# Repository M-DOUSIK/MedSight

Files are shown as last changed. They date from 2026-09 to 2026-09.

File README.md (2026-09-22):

# MedSight

**An offline medication dispenser and adherence recorder.**
Most dispensers release pills and assume the rest. This one measures who took
them and how many came out.

Built on µT-Kernel 3.0 and an STM32N6570-DK, with no radio of any kind in this
build - connectivity is planned work, not a rejected idea.

**TRON Programming Contest 2026 · RTOS Application category ·
Entry 54916**

🔗 **[m-dousik.github.io/MedSight](https://m-dousik.github.io/MedSight/)** - the
project site, with the device running.

---

A carer enrols a patient once - face, name, dose size and the times of day they
take it - behind a passcode. From then on the device recognises the patient by
face, reminds them when a dose is due, turns a stepper-driven turntable while an
infrared sensor counts each pill physically leaving it, runs action recognition
over the confirmation window, and writes what happened to a local SD card.

**It counts pills leaving the turntable and corroborates a swallowing gesture. It
cannot prove that a medication was ingested.** No device of this class can. The
action recognition is corroboration only, by design, and the button confirms
every dose. [`docs/MEDSIGHT_HANDBOOK.md`](docs/MEDSIGHT_HANDBOOK.md) is the full account
and is the document to read first.

---

## Where to start

| If you are... | Read |
|---|---|
| **new to this** | [`docs/MEDSIGHT_HANDBOOK.md`](docs/MEDSIGHT_HANDBOOK.md) - what the device is, how it works, how to run it, how to build and flash it, and what comes next. Also the copy printed and shipped in the box: [print edition PDF](pdf/MedSight_Handbook_PRINT.pdf) |
| **looking at the hardware** | [`docs/HARDWARE_SPEC.md`](docs/HARDWARE_SPEC.md) - annotated parts, wiring, bill of materials, specifications |
| **evaluating the engineering** | [`docs/TECHNICAL_REFERENCE.md`](docs/TECHNICAL_REFERENCE.md) - software, AI, memory, and every measured number with how it was obtained |
| **checking provenance** | [`docs/THIRD_PARTY_SOFTWARE.md`](docs/THIRD_PARTY_SOFTWARE.md) and [`docs/LICENSING.md`](docs/LICENSING.md) |
| **holding a device whose mechanism will not move** | [`docs/MEDSIGHT_HANDBOOK.md`](docs/MEDSIGHT_HANDBOOK.md) 8.9. One macro and a rebuild runs everything except the physical dispense, with no motor, driver or sensor attached |

**Six documents.** The handbook is also a print edition:
[`pdf/MedSight_Handbook_PRINT.pdf`](pdf/MedSight_Handbook_PRINT.pdf).

## The numbers

Every figure is measured on the real board and named with how it was obtained
in [`docs/TECHNICAL_REFERENCE.md`](docs/TECHNICAL_REFERENCE.md). None
is an estimate.

| | Measured |
|---|---|
| **CPU idle** | **~89.6%** of wall-clock time asleep in `WFI`, waking ~980×/s. The vendored BSP ships `low_pow()` **empty** |
| **Face recognition** | **209 ms** end to end - detector, embedder and the RTOS IPC between them - **identical to the millisecond across four captures** with different faces and confidences |
| **Memory footprint** | `.text` 561,324 · `.rodata` 334,456 · `.data` 684 · `.bss` 656,488 - 85.6% of the code region, 63.0% of the data region |
| **Pill detector** | 8-bit integer on the NPU with the decode on the Cortex-M55. The quantisation matches floating point on the validation set; at the deployment distance per-frame detection is about 7%, so it corroborates rather than decides |
| **IR pill counting** | real pulses **17-46 ms**, chatter 0-1 ms, floor set at 8 ms - all measured before any threshold was chosen |
| **Dispense counting** | 4 trials, all 13 pills counted by the sensor rather than by the motor. A small sample, and not a reliability figure: the mechanism has miscounted and jammed outside these trials |
| **µT-Kernel surface** | tasks, event flags, alarm handlers, a message buffer, one mutex and the idle hook. Every call lives in `ms_osal.c`; the vendored kernel is unmodified except for six files, none of which implements a system call |
| **The assembled unit** | **165 x 169 x 204 mm** and **950 g** with the turntable empty, tape measure and kitchen scales against the built device. 15 mm of the depth is the collection drawer standing proud of the body |

The 209 ms is the same on every capture: four images, four detector
confidences, one timing. The Neural-ART runtime executes a fixed epoch schedule
for a fixed input shape, so the cost does not depend on image content, which is
why the display holds still for the capture window instead of showing a
spinner.

## What makes this a µT-Kernel application, specifically

The category is judged on real-time performance, power saving and memory
footprint. The answer is not "we used an RTOS":

| Primitive | What it does here |
|---|---|
| `tk_cre_tsk` | **Six tasks**, priorities derived rate-monotonically. The AI task sits *below* the interface deliberately, which is what keeps touch and the physical button alive while the accelerator works |
| `tk_cre_flg`, `tk_wai_flg` | **Inference is dispatched through an event flag.** One blocking call distinguishes face found, no face, and no answer at all. A queue, a semaphore or a mutex cannot say that |
| `tk_cre_alm`, `tk_sta_alm` | **Dose scheduling is an alarm handler**, not a task polling the clock. Polling would wake 8,640 times a day in order to act four times. The handler sets one bit and returns; every line of real work is done by a task |
| `tk_cre_mbf`, `tk_cre_mtx` | The logger's queue, so no caller ever waits on an SD write, and the firmware's one mutex: the clock, which has two readers |
| `low_pow()` | The vendored board support package ships its idle hook **empty**. Ours executes `WFI` and accounts for the cycles, which is where the 89.6% comes from |

**A single file reaches the kernel.** Every call above lives in `ms_osal.c`, behind
an abstraction the rest of the firmware was written against, so the kernel's
use is deliberate and in one place rather than scattered. Two idioms were
evaluated and deliberately not adopted, with the reasoning recorded: a
fixed-size memory pool, and an event flag for the confirm state. Neither would
have done any work here.

## The AI, and which models are ours

| Network | Decides | Origin | Licence |
|---|---|---|---|
| CenterFace | Detects a face and emits five landmarks with it, both mouth corners among them | STMicroelectronics | SLA0044 |
| MobileFaceNet | Encodes the face crop as a 128-dimension embedding for cosine matching | STMicroelectronics | SLA0044 |
| MediaPipe hand landmarks | 21 keypoints, giving the fingertip position during the confirmation window | Google. **Not ours** - we selected, quantised, compiled and integrated it; we did not train it | Apache-2.0 |
| **Pill detector** | Single-class detection in a mouth-centred region. Corroboration only | **Trained by this project** | AGPL-3.0, from the training framework, [resolved](docs/LICENSING.md) |

Everything around the face networks is this project's code: the frame snapshot,
the CenterFace box decode, L2 normalisation, int8 quantisation, cosine gallery
matching and SD persistence.

The pill detector was trained here on a public pill dataset, exported, and
adapted to the accelerator: the convolutional body runs as 8-bit integer on the
NPU and the YOLO decode runs on the Cortex-M55. On the validation set the 8-bit
model matches the floating-point one it was trained from, but at the deployment
distance a pill is about an 8-pixel object and per-frame detection is around
7%, so it corroborates the hand geometry rather than deciding on its own.

It carries **AGPL-3.0** because Ultralytics YOLOv8 trained it and that licence
follows the weights, so the whole training pipeline is published with them in
[`tools/pill_detector/`](tools/pill_detector/).

## Data handling

**This build has no radio.** Wi-Fi, Ethernet and BLE are never initialised,
and no code path can transmit anything off-device.

**Connectivity is planned work**: a carer alert over Wi-Fi when a dose is
missed, and a patient-worn band that signals when a dose is due. The handbook's
last part sets out what that has to answer first: transport security, what the
message carries, where the data comes to rest, provisioning, and what happens
when the link is down.

**What follows from having no radio today:** patient names, face embeddings
and the adherence log cannot leave the SD card over a network, because there is
no network. That is a consequence of the scope decision rather than its motive,
so it changes when the radio arrives.

**The unit as shipped has no card fitted.** Its slot is on the board, inside
the housing, and the card is supplied alongside rather than installed. Until it
is fitted the home screen says so in those words, nothing is recorded, and the
enrolled gallery and the carer passcode last only until the power is cut.
Everything else runs exactly as described.

Face embeddings are never written to UART or to any log; only names, gallery
slot indices, dose counts, schedule times and match confidences are. That rule
was checked against a captured UART log from the noisiest build that exists,
not only by reading the source.

The patient record is five fields: a validity flag, a name, a 128-byte
embedding, a dose size, and up to four dose times. No phone number, no address,
no date of birth, no medical history. What is stored for face recognition is a
quantised embedding, **not the enrolment photograph** - the camera frame that
produced it is never written to the card.

Full posture, including the gaps, in
[`docs/MEDSIGHT_HANDBOOK.md`](docs/MEDSIGHT_HANDBOOK.md).

## Building it

This firmware starts from ST's STM32N6 example application and replaces its
core: µT-Kernel 3.0 is the RTOS, and the OS abstraction layer, the interface,
the state machine, the scheduler, the logger and the dispenser driver are
original MedSight code. Every third-party component and its licence is
inventoried in [`docs/THIRD_PARTY_SOFTWARE.md`](docs/THIRD_PARTY_SOFTWARE.md).

**STM32CubeIDE 2.1.1** or newer. There is **no `.ioc` file** - every peripheral
is configured in code rather than generated, so there is nothing to
regenerate.

```
firmware/STM32CubeIDE/FSBL     <- import this, build Debug
```

Expect **0 errors, 0 warnings**. Both `MEDSIGHT_PHYSICAL_DISPENSER` 1 and 0
build clean; `0` runs the whole application with **no dispensing hardware
attached**, which is a supported configuration rather than a debug path. That
branch is the earlier on-screen dispense kept byte-for-byte, and it has been
run on the assembled board rather than only compiled.

> **Building is not enough to get a working device.** The NPU weights live in
> external flash and the linker marks those regions `(NOLOAD)`, so the
> application build never writes them. Flash the five images in
> [`weights/`](weights/) once per board, then power-cycle. Without them the
> firmware runs and both AI features return nonsense, **with nothing in the log
> to say why.**

Complete instructions, every command of which was actually run:
[`docs/MEDSIGHT_HANDBOOK.md`](docs/MEDSIGHT_HANDBOOK.md) Part 3.

## Licence - is this open source?

**Yes.** MedSight's own code, documentation and CAD are released under
**Apache-2.0**, an OSI-approved open-source licence: read it, build it, change
it, ship it, including commercially, keeping the notice.

The repository is more a **shelf** than a **book** - every item carries its own
licence, and one of them is not open source: ST's AI runtime, camera ISP and
the two face models are under **ST SLA0044**, which permits free redistribution
for use on ST hardware but is not an open-source licence. Every STM32 AI project
carries that, and it blocks nothing.

**MedSight's own code is Apache-2.0.** The repository is **not licensed as a
single work** - it vendors µT-Kernel under T-License, ST components under
BSD-3-Clause and SLA0044, a Google model under Apache-2.0, and FatFs under its
own licence.

[`docs/LICENSING.md`](docs/LICENSING.md) is the per-file map, and it also
**resolves the AGPL-3.0 question** on the pill detector rather than leaving it
open: the project adopts Ultralytics' own stated reading, complies with it for
the detector's artefacts, licenses its own code permissively so the question
cannot bind anything else, and names the one residual incompatibility along with
the build-verified configuration that avoids it.

## Layout

```
MedSight/
  index.html, site.css   the project site (GitHub Pages serves this)
  media/                 the hero loop and its poster
  firmware/              the complete firmware - build this
  hardware/cad/          STL files for the three printed assemblies
  weights/               NPU weight blobs, addresses and fingerprints
  docs/                  everything above, and the engineering record
  pdf/                   the handbook, print edition
  research/              the evidence base, with licences
  tools/                 the model training pipeline and asset generators
```

**The handbook is also a print edition**, laid out to be read rather than
filed: [`pdf/MedSight_Handbook_PRINT.pdf`](pdf/MedSight_Handbook_PRINT.pdf).

## Where it stands

It is a working prototype, and four things are not finished. Each has a plan,
and the handbook's last part sets all of them out properly.

- **One turntable, so one medication.** Next: the stacked dispensing modules already drawn
  in the hardware specification, plus a drug field in the patient record. The
  interface draws the extra slots today, greyed out.
- **It cannot see how full the turntable is.** Next, and the cheapest of these: a
  carer-entered fill count, decremented by *counted* pills, shown as a low
  stock warning on screens that already exist.
- **A missed dose cannot leave the room**, because there is no radio in this
  build. Next, and the top of the list: a carer alert over Wi-Fi and a
  patient-worn band, with the security design that has to come with them.
- **The housing does not lock.** Next: a lockable enclosure, tamper detection
  and a vibration sensor, so the log can say when the unit was disturbed.

And one thing to be clear about rather than plan around: the device counts
pills out and corroborates a swallowing gesture. It cannot prove somebody
swallowed, and no device of this class can, which is why the patient's button
press stays the confirming action.

## Credit

MedSight was built by five of us.

| | |
|---|---|
| **Dousik Manokaran** (applicant) | The firmware: the µT-Kernel migration, the six-task architecture and its priorities, the four networks on the accelerator, and the documentation |
| **Howard Nikhil** | The physical dispensing hardware: the turntable, the infrared pill counter, and the bench work the counting design rests on |
| **Gaurav V R** and **Dillimaran K** | The three-stage intake pipeline - detection, geometry, temporal decision - and the guarded state machine that refuses to certify an intake it cannot support |
| **Abirami M** | The visual identity: the mascot, and the artwork all twenty-two screens are cut from |
| **Dr. G. Santhanamari** and **Dr. D. Selvakumar** | Supervision, and two roadmap items: the vibration sensor for tamper detection, and the patient-worn alert band |

Our thanks to the TRON Forum for the opportunity, and for the STM32N6570-DK
board that made the second round possible.

µT-Kernel 3.0 is (c) TRON Forum and Ken Sakamura, under T-License 2.1 /
2.2, and the STM32N6570-DK was supplied by the TRON Forum for the second round.

Third-party components and their licences are inventoried in
[`docs/THIRD_PARTY_SOFTWARE.md`](docs/THIRD_PARTY_SOFTWARE.md).

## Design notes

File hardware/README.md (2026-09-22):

# hardware/

The hardware **documents** live in `../docs/`, with everything else, so that
every relative link between documents resolves the same way:

| Document | What it is |
|---|---|
| [`../docs/HARDWARE_SPEC.md`](../docs/HARDWARE_SPEC.md) | **the whole hardware document** - annotated parts view, the eleven wires, the bill of materials, the specifications block, the power path and the bring-up order |
| [`../docs/MEDSIGHT_HANDBOOK.md`](../docs/MEDSIGHT_HANDBOOK.md) | Part 4 is the same material laid out for somebody holding a jumper wire |

This directory holds the **files**: `cad/` for the printed parts.

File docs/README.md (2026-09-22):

# docs/

| Document | What it is |
|---|---|
| [`MEDSIGHT_HANDBOOK.md`](MEDSIGHT_HANDBOOK.md) | **Start here.** What the device is, how it works, how to run it, how to build and flash it, and what comes next. Also the print edition, [`pdf/MedSight_Handbook_PRINT.pdf`](../pdf/MedSight_Handbook_PRINT.pdf) |
| [`HARDWARE_SPEC.md`](HARDWARE_SPEC.md) | Annotated parts, the eleven wires, the bill of materials, the specifications, the power path and the bring-up order |
| [`TECHNICAL_REFERENCE.md`](TECHNICAL_REFERENCE.md) | Part A the RTOS, Part B the software structure, Part C the AI pipeline, Part D memory, Part E every measured number and how it was obtained |
| [`THIRD_PARTY_SOFTWARE.md`](THIRD_PARTY_SOFTWARE.md) | Name, rights holder, acquisition and function of every third-party component, the µT-Kernel modification table, and the rights guarantee |
| [`LICENSING.md`](LICENSING.md) | Which licence governs which files, and whether this project is open source |
| [`PROGRAM_PLAN_RECONCILIATION.md`](PROGRAM_PLAN_RECONCILIATION.md) | What the March 2026 plan promised against what was built, in both directions |

Also here: [`slides/`](slides/), the introduction slides as a PowerPoint
file, and [`images/`](images/).

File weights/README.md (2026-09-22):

# NPU weights - what to flash, where, and why the firmware is useless without it

Everything in this directory is **NPU model data that the firmware build does
not contain**. The linker marks the external NOR regions `(NOLOAD)` on purpose,
so building and flashing the application never writes any of it.

That means a fresh clone can compile a perfectly good `.elf`, flash it, and get
a device whose face recognition and action recognition both produce garbage -
with nothing in any log to say why. **Flash these once per board.**

## The five images

| file | address | bytes | what it is |
|---|---|---|---|
| `fd_data.xSPI2.bin` | `0x70380000` | 2,030,881 | CenterFace - face detector constant pools |
| `ec_blobs.xSPI2.bin` | `0x71000000` | 296,832 | NPU epoch-controller microcode, **both** face networks |
| `faceid_data.xSPI2.bin` | `0x72000000` | 1,092,129 | MobileFaceNet - face embedder constant pools |
| `hand_atonbuf.xSPI2.bin` | `0x73000000` | 3,221,233 | MediaPipe hand landmarks, decides a dose |
| `pill_atonbuf.xSPI2.bin` | `0x73400000` | 3,049,169 | YOLOv8n pill detector, corroboration only |

SHA-256 prefixes, so a mis-copied file is caught before it becomes a debugging
session:

```
8076b74352f3c323  ec_blobs.xSPI2.bin
68a41c8a030afde3  faceid_data.xSPI2.bin
44f72b41a1f43183  fd_data.xSPI2.bin
a0cb24315860ddae  hand_atonbuf.xSPI2.bin
e1359bb6add1268f  pill_atonbuf.xSPI2.bin
```

## Flashing

```powershell
$cli    = "C:\ST\STM32CubeIDE_2.1.1\STM32CubeIDE\plugins\com.st.stm32cube.ide.mcu.externaltools.cubeprogrammer.win32_2.2.500.202603051304\tools\bin\STM32_Programmer_CLI.exe"
$loader = "C:\ST\STM32CubeIDE_2.1.1\STM32CubeIDE\plugins\com.st.stm32cube.ide.mcu.externaltools.cubeprogrammer.win32_2.2.500.202603051304\tools\bin\ExternalLoader\MX66UW1G45G_STM32N6570-DK.stldr"

& $cli -c port=SWD mode=UR -el $loader -w "weights\fd_data.xSPI2.bin"        0x70380000
& $cli -c port=SWD mode=UR -el $loader -w "weights\ec_blobs.xSPI2.bin"       0x71000000
& $cli -c port=SWD mode=UR -el $loader -w "weights\faceid_data.xSPI2.bin"    0x72000000
& $cli -c port=SWD mode=UR -el $loader -w "weights\hand_atonbuf.xSPI2.bin"   0x73000000
& $cli -c port=SWD mode=UR -el $loader -w "weights\pill_atonbuf.xSPI2.bin"   0x73400000
```

### `mode=UR`, not `mode=HOTPLUG`

This page said `mode=HOTPLUG` for two years, and it was right for two years:
the only writes happened before any application existed on the board, and
HOTPLUG avoids holding the MCU in reset while the external loader talks to the
flash chip.

Once a bootable MedSight image went into external flash, that changed. HOTPLUG needs a live, responsive core to attach to - and with
MedSight **running**, the erase fails outright, because the application has
XSPI2 memory-mapped for these very weights while the loader wants the same bus
in indirect mode.

**Use `mode=UR` for writes to external flash.** It holds the target in reset,
so it does not care what the application was doing. The commands above have
been updated.

### Then POWER-CYCLE. Unplug the USB cable.

Not a reset, not the IDE's stop button - the cable, out, for a few seconds.

Back-to-back external-loader operations leave the flash chip's live bus state
confused, and the symptom is a boot that hangs where XSPI is first touched:
the log stops right after `ai_vision_init: DEBUG build (-O0).`, before
`HAL_CACHEAXI_Enable`, and the LCD holds a stale frame. The flash *contents*
are fine; only the peripheral's bus state needs clearing.

**This applies to reads as well as writes.** A `-r32` verification read leaves
the bus in the same state a write does, and a read is exactly when it is most
tempting to leave the board running.

### Verifying

```powershell
& $cli -c port=SWD mode=UR -el $loader -r32 0x73000000 2
```

Compare against the file's own first words, then power-cycle again:

```bash
python -c "import struct;print('0x%08X 0x%08X' % struct.unpack('<II', open('weights/hand_atonbuf.xSPI2.bin','rb').read(8)))"
```

`0x73000000` should read `0xB317E9A4`, `0x73400000` should read `0xF0010DF7`.

## Confirming it worked

A correct boot says, in this order:

```
ai_vision_init: face detector + embedder ready.
ARENA SELFTEST PASS: 225280 bytes writable and readable
intake: hand landmark model ready (MediaPipe 224x224 INT8, 21 keypoints, ...)
intake: pill detector ready (YOLOv8n 160x160 INT8, head cut, decode on CPU).
```

A missing or wrong image usually does **not** announce itself as a flash
error - it shows up as a network that initialises and then returns nonsense.
If detection runs but the numbers are meaningless, suspect a weight region
before suspecting the code.

## Where these come from

* **`fd_data`, `faceid_data`, `ec_blobs`** - generated once and unchanged
  since. Byte-identical across every build that used them, which is how the
  copies here were validated. The epoch-controller data's source of
  truth is the tracked headers `FSBL/Inc/fd_ecblobs.h`, `faceid_ecblobs.h` and
  `network_ecblobs.h`; `ec_blobs.xSPI2.bin` is a packaging of the same content
  for the programmer.
* **`hand_atonbuf`** - ST model zoo `pose_estimation/handlandmarks`,
  Apache-2.0, regenerated against `medsight_hand.mpool`.
* **`pill_atonbuf`** - the hard-negative retrain, regenerated against
  `medsight_pill2.mpool` so it does not collide with the hand model.

Regenerating either model is in `tools/pill_detector/build_pill_detector.py`. Note
that a regenerated model changes its INT8 quantisation scales, which live in
`Inc/stai_*.h` - **so a weights change always requires a firmware rebuild**,
even though the firmware does not contain the weights.

## Why this directory exists at all

These blobs used to live only inside `firmware/STM32CubeIDE/FSBL/Debug/
weights_flash/`, i.e. inside build output. When build output stopped being
tracked, that silently removed the only copies of the face-network weights
from the repository. The check that authorised the removal looked for
hand-written source and found none, which was the wrong question: not
hand-written is not the same as regenerable, and for the face networks there
is no regeneration path in this repository at all.

Irreplaceable binary assets do not belong in a directory that a `.gitignore`
rule can sweep away.

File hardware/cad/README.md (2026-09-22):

# The printed parts

Three printed assemblies, designed in Autodesk Fusion.

Each part is here twice: an **STL** to print from, and a **STEP** to open and
change. The STL is a triangle mesh and cannot meaningfully be edited; the STEP
carries the solid geometry.

| Part | Print | Edit | Size (STL bounding box) | Triangles |
|---|---|---|---|---|
| Board enclosure | `board_enclosure.stl` | `board_enclosure.step` | **164.24 × 153.00 × 151.99 mm** | 10,766 |
| Pill dispenser mechanism | `pill_dispenser.stl` | `pill_dispenser.step` | **179.24 × 92.00 × 50.00 mm** | 5,136 |
| Structural pillars, 8 off | `structural_pillars.stl` | `structural_pillars.step` | **180.00 × 100.00 × 10.00 mm** | 96 |

`HARDWARE_DESIGN_SHEET.pdf` is a one-page annotated summary of all three.

Numbered callouts for every sub-part, and what each one does, are in
[`../../docs/HARDWARE_SPEC.md`](../../docs/HARDWARE_SPEC.md).

Printed FDM in PLA at 20% infill.

## Licensing

Original designs by this project, under **Apache-2.0**, the same as the rest of
MedSight's own work. See [`../../docs/LICENSING.md`](../../docs/LICENSING.md).

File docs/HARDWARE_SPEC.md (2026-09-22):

# The hardware, part by part

Parts, wiring, bill of materials, specifications and the order to power things
up in.

---

## 1. The annotated view

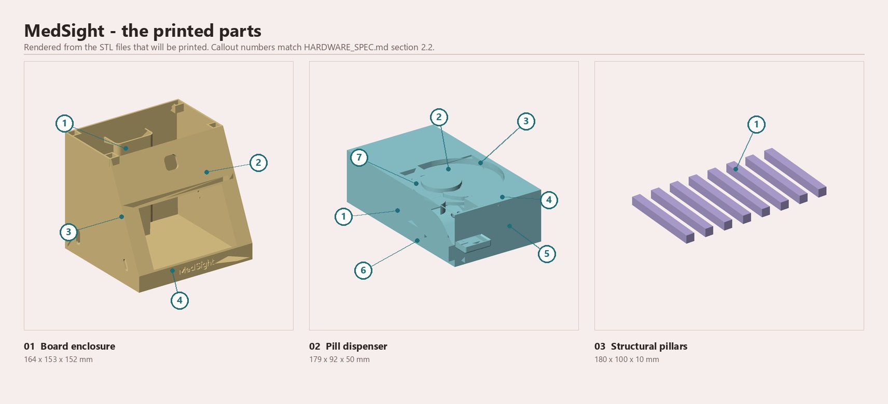
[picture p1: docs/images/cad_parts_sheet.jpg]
The three printed parts, rendered from their STL files with numbered callouts


*The three printed assemblies. Callout numbers resolve to the tables in
section 2.*

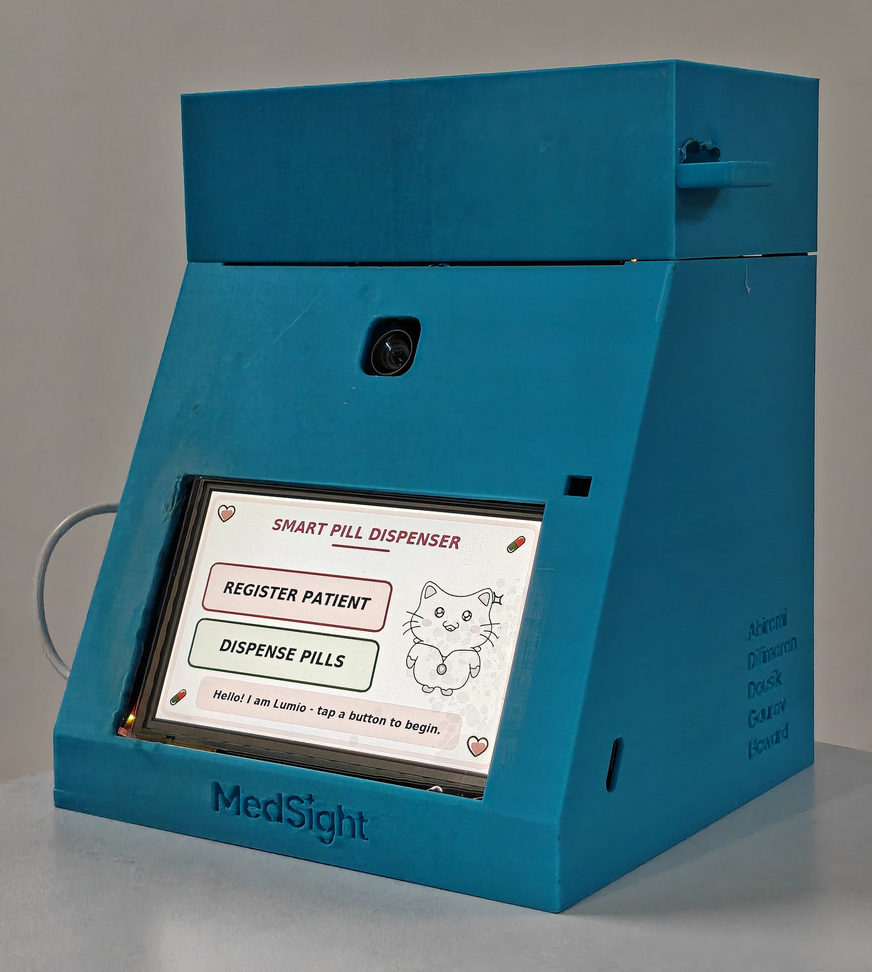
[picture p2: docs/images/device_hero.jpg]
The assembled device seen from the front left, the 5 inch screen lit on the home screen with its two buttons, the camera above the screen and the MedSight name on the front base


*The assembled unit. The camera sits above the screen, the collection drawer is
at the lower right, and the five names on the side panel are the people who
built it.*

---

## 2. Parts, by callout number

Every number in the annotated view resolves to a row here. The board's own
components are listed too, so that what was used and what was merely present
are both visible.

### 2.1 Electronics

| # | Part | Manufacturer / part number | Qty | Function | Source |
|---|---|---|---|---|---|
| **1** | STM32N6570-DK Discovery kit | STMicroelectronics, **STM32N6570-DK** (MCU: STM32N657X0H3Q) | 1 | The whole computer: Cortex-M55 at 800 MHz, Neural-ART NPU at 1 GHz, ~4.2 MB on-chip SRAM. Runs µT-Kernel 3.0 and all four networks. | Supplied by the contest for round 2 |
| **2** | 5" LCD with integrated capacitive touch | **RK050HR18** panel + **GT911** touch controller (both on the DK) | 1 | The entire user interface: 22 screens at 800×480 RGB565, scanned out by the LTDC. Touch on I2C2 (PD14/PD4). | On the DK board |
| **3** | Camera module | **IMX335** sensor on ST's MB1854 / B-CAMS-IMX bundle, via DCMIPP + CSI | 1 | Face capture for recognition and enrolment; the intake watch during the confirm screen. | Shipped with the DK |
| **4** | microSD card | any FAT32 card, on the DK's SDMMC2 slot | 1 | The only storage: patient gallery `patients.dat`, append-only `events.log`, carer passcode hash `carer.cfg`. **Nothing leaves this card.** | User-supplied |
| **5** | Stepper motor | **28BYJ-48**, 5 V, unipolar, 1/64 geared | 1 | Turns the turntable. Driven in a half-step sequence; each half-step is one atomic `BSRR` write. | Sold as a pair with (6) |
| **6** | Darlington driver board | **ULN2003A** on the common 4-LED breakout | 1 | Switches the four motor coils from four 3.3 V GPIO lines. The four channel LEDs are a free bring-up indicator. | ships with (5) |
| **7** | IR proximity module | 3-pin digital module, **`OUT` not analog** | 1 | Counts each pill as it physically passes. This is the sensor the whole dispense loop closes around - the progress bar is a readout of this interrupt, not a timer. | generic |
| **8** | Piezo buzzer | **active** piezo element (contains its own oscillator) | 1 | Five alert patterns. Driven by plain push-pull GPIO, DC switched - no PWM, no timer channel, no transistor, no resistor. | generic |
| **9** | Jumper wires | female-to-female | **11** | The entire wiring harness. **No resistors, no transistors, no level shifters, no external regulator.** Buy 14 - they are sold in packs and they break | generic |
| **10** | USB-C cable + 5 V supply | any; a 10 000 mAh / 22.5 W USB battery pack was used | 1 | Single supply for board, driver and sensor. One 5 V source, one ground. | generic |

**Why there are no external passives.** An early design called for pull-down
resistors on the ULN2003 inputs. Checking TI's datasheet **SLRS027T** section 7.2-7.3
showed the ULN2003A has an **internal input network** - 2.7 kΩ series plus
7.2 kΩ/3 kΩ base-emitter pull-downs - so the inputs do not float. The
requirement was dropped, and the bill of materials is the shorter for it.

### 2.2 Printed and mechanical parts

Three printed assemblies. Every dimension is the STL bounding box.

#### 01 - Board enclosure · 164 × 153 × 152 mm · 10,766 triangles

Houses the STM32N6570-DK and presents the 5" screen at a readable angle. The
sloped front face is the reason the device reads as an appliance rather than a
dev board on a desk.

| # | Part | Function |
|---|---|---|
| **1** | Outer housing shell | The main enclosure body, with sloped structural walls |
| **2** | Port / connector grid | A grid of circular openings on the side wall for the I/O the board needs to reach - USB-C, the jumper harness out to the dispenser |
| **3** | Battery compartment | Rear-mounted cuboid recess for the battery pack. **This is what makes standalone operation a product feature rather than a demo**: the battery lives inside the device rather than trailing from it |
| **4** | MedSight brand plate | Embossed panel on the front base face |

#### 02 - Pill dispenser · 179 × 92 × 50 mm · 5,136 triangles

The mechanism. One turntable, one medication - which is where classification
happens in this device, mechanically rather than by vision.

| # | Part | Function |
|---|---|---|
| **1** | Outer enclosure box | Rectangular housing, open at the top over the turntable |
| **2** | Rotating pill carousel | The disc, with a helical pill track. Mounted on the 28BYJ-48 and driven half-step |
| **3** | Central drive motor hub | The spindle at the centre, coupling the stepper to the carousel |
| **4** | Dispensing chute | The exit channel to the collection drawer. **The chute geometry is what makes the IR counter work**: pills *slide* rather than free-fall, which is why detection pulses measure 17-46 ms instead of the few milliseconds a drop would give - and a driver sized for a free-fall would have discarded every real pill |
| **5** | Output collection drawer | The external box the dose arrives in |
| **6** | Side sensor brackets ×2 | Mounts that hold the infrared proximity module square to the chute at a repeatable height and standoff, which is what makes one pill's pulse look like the next one's |
| **7** | Internal divider wall | Vertical partition separating the mechanism from the pill storage volume |

#### 03 - Structural pillars · 180 × 100 × 10 mm · 8 off

| # | Part | Function |
|---|---|---|
| **1** | Structural pillar ×8 | Hollow rectangular-section beams forming the frame that carries the enclosure and the dispenser as one assembly |

### 2.3 The mechanism, and the stacked-module design it belongs to

**The turntable was designed and built by the team.** A small turntable with
passive guides singulates loose, unsorted pills into a single-file row, pushes
that row past an infrared proximity sensor, and drops counted pills down a chute. Pills
go in loose; the guides do the sorting mechanically, so there is no per-pill
compartment to align.

**One reflective sensor, with the threshold in hardware.** The module is a
reflective infrared proximity sensor: a pill passing in front of it returns
enough light to pull the output low, and because the output is digital the
in-or-out decision is made in the sensor rather than in software. One module
also means one alignment to hold rather than a facing pair to keep square.

**What that costs, stated rather than skipped.** How strongly a pill returns
light depends on its colour and finish, so this is not a sensor that is
indifferent to what is being counted. That is precisely why the discrimination
floor was set from measured pulse durations on the bench rather than assumed,
and why the counter is bounded by time since the last counted pill rather than
by an expected pulse shape.

**The stepper is a 28BYJ-48 through a ULN2003A**, driven directly in a half-step
coil sequence rather than through a STEP/DIR driver IC. It is cheap, it draws
little, it needs four GPIO lines, and it is trivial to duplicate per module.

#### The stacked-module architecture, which is design intent and not built

One module is built and works. The intended product is **six to eight
stacked independent dispensing modules**, each a duplicate of the one that exists, all
dropping into **one shared chute** so the patient collects a dose from a single
place.

Stacked independent modules were chosen over one larger multi-position carousel
for a reason that was about the deadline as much as the engineering: **you can
build two today and six later without redesigning anything.** A single large
carousel has to be built to full capacity before it is useful at all, its
capacity is fixed at print time, and one jam stops every medication rather than
one. The dispense API already takes a count and returns what was actually
counted, so adding a `module_id` is additive.

Turntable and guide geometry is the one part that is *not* copy-paste between
modules, because different medications have different pill sizes.

**The CAD files are in [`hardware/cad/`](../hardware/cad/)**, one STL and one
STEP per printed part: the STL is what a reader prints, the STEP is what a
reader can open and change. The print settings actually used are recorded in
`hardware/cad/README.md`. What is still missing there is a fastener list.

---

## 3. Interface and connector map

Wire by the **silkscreen label** printed next to each pin - that is the only
labelling that is unambiguous with a jumper in your hand. The MCU-pin column
exists so the table can be checked against `dispenser.c` and `buzzer.c`.

| Function | Silkscreen | Header | MCU pin | I/O domain |
|---|---|---|---|---|
| ULN2003 `IN1` - coil A | `D3` | CN11 | PE9 | VDDIO5 |
| ULN2003 `IN2` - coil B | `D5` | CN11 | PE10 | VDDIO5 |
| ULN2003 `IN3` - coil C | `D6` | CN11 | PE13 | VDDIO5 |
| ULN2003 `IN4` - coil D | `D9` | CN12 | PE14 | VDDIO5 |
| IR module `OUT` | `D2` | CN11 | PD0 (**EXTI0**, both edges) | main VDD |
| Piezo `+` | `D10` | CN12 | PA3 | main VDD |
| 5 V and GND for both modules | `5V` / `GND` | CN8 | - | - |

**Pins that must stay unwired:**

| Pin | MCU pin | Why |
|---|---|---|
| `D14` | PC1 | camera I2C1 SDA - in use |
| `D15` | PH9 | camera I2C1 SCL - in use |

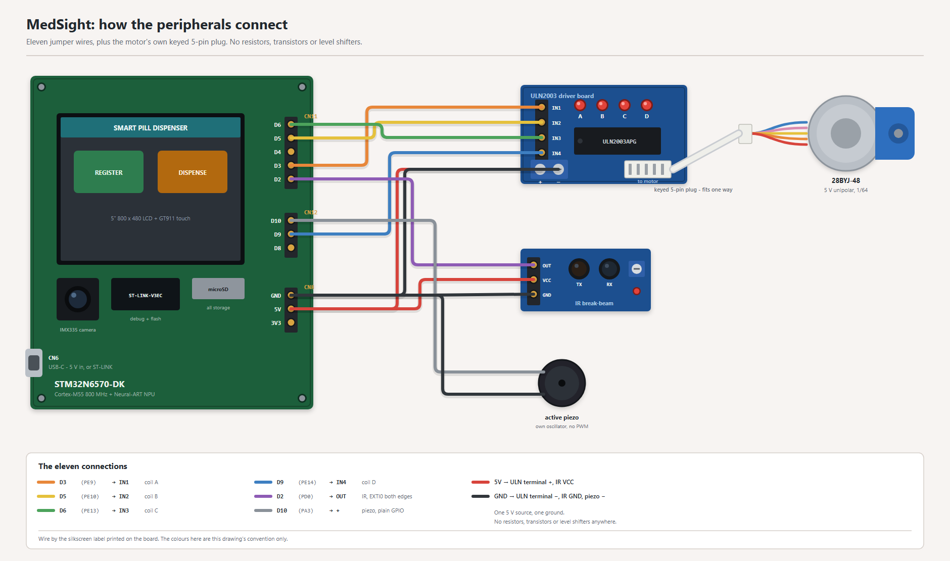
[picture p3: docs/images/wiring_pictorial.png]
How the peripherals connect


*Eleven jumper wires, plus the motor's own keyed 5-pin plug. Wire by the
silkscreen label - the colours above are the drawing's own convention. Generated
from the table above by `submission/render_wiring.py`, so the two cannot
disagree.*

Power path: section 9. Bring-up order: section 10.

---

## 4. Specifications

| | |
|---|---|
| **Processor** | Arm Cortex-M55 @ 800 MHz, STM32N657X0H3Q |
| **AI accelerator** | ST Neural-ART NPU @ 1 GHz, ~600 GOPS INT8 |
| **Networks running on it** | **4** - CenterFace (face detection), MobileFaceNet (face embedding), MediaPipe hand landmarks 224×224 INT8, YOLOv8n single-class pill detector 160×160 INT8 |
| **On-chip memory** | ~4.2 MB AXI SRAM in six banks; 220 KB proven NPU-reachable arena at `0x34388000` |
| **External memory** | 1 Gbit Octo-SPI NOR (NPU weights, four regions) · 256 Mbit Hexadeca-SPI PSRAM (activation scratch, camera frames) |
| **Firmware footprint (Debug)** | `.text` 561,324 · `.rodata` 334,456 · `.data` 684 · `.bss` 656,488 B - **85.6%** of the code region (147 KB free), **63.0%** of the data region (378 KB free) |
| **RTOS** | µT-Kernel 3.0 BSP2, six tasks, rate-monotonic priorities |
| **CPU idle** | **~89.6%** of wall-clock time in `WFI`, waking ~980×/s |
| **Display** | 5" RK050HR18, **800 × 480, RGB565**, LTDC scan-out, single framebuffer at `0x34200000` |
| **Touch** | GT911 capacitive, I2C2 |
| **Camera** | Sony IMX335 via DCMIPP + CSI |
| **Storage** | microSD (SDMMC2), FAT32 via FatFs R0.15. **The only persistent storage in the device.** |
| **Clock** | Internal RTC on LSE, falling back to LSI; kept across resets in the backup domain. **No NTP - there is no network.** |
| **Actuator** | 28BYJ-48 unipolar stepper, 1/64 gearbox, driven **half-step**; `MS_STEP_PERIOD_MS` = **2 ms** per half-step |
| **Pill sensor** | 3-pin digital IR proximity on EXTI0, both edges timestamped in the ISR. Idle **HIGH**. Real pill pulses **17-46 ms**; contact chatter 0-1 ms; discrimination floor **8 ms** |
| **Dispense bound** | `MS_NO_PILL_TIMEOUT_MS` = **25 s** since the *last counted pill* - a working mechanism runs as long as it needs to; a stopped one is caught in one window |
| **Audio** | Active piezo, 5 patterns, DC-switched GPIO. No codec, no PWM |
| **Power input** | 5 V over USB-C (CN6). Board, driver and sensor from one supply, one ground |
| **Power consumption** | **not measured.** See section 6 |
| **Boot modes** | **A** - development boot over USB with UART log. **B** - standalone from external NOR: ST FSBL at `0x70000000`, MedSight signed `-t ssbl` at `0x70100000`. Verified running a complete dispense on battery with no laptop |
| **Connectivity** | **None in this build.** Wi-Fi, Ethernet and BLE are never initialised and no network stack is compiled in. A scope decision, not a principle - connectivity is planned work, `MEDSIGHT_HANDBOOK.md` section 6.8 |
| **Capacity** | **multiple patients**, 4 dose times each, 1-10 pills per dose, **1 turntable**. The gallery is sized by `MAX_PATIENTS` in `ai_vision.h`, 10 in this build; raising it costs gallery RAM and nothing else |
| **Printed part sizes** | Board enclosure **164 × 153 × 152 mm** · pill dispenser **179 × 92 × 50 mm** · structural pillars **180 × 100 × 10 mm** (8 off), read from the STL bounding boxes |
| **Assembled dimensions** | **165 x 169 x 204 mm** (W x D x H), tape measure against the assembled unit. 15 mm of the depth is the collection drawer, which stands proud of the body |
| **Mass** | **950 g**, assembled, turntable empty |
| **Turntable capacity** | **Not a fixed number, by the nature of the mechanism.** Pills lie loose in a single layer on an open turntable and the guides singulate them, so there is no point at which it fills and binds. How many go in depends on pill size and how tidily they are laid out |
| **Power-source jumper** | On the underside of the board, selecting `VIN`, `USB-C` or `STLK`. **USB-C** to run from the battery, **STLK** to build and flash over the debugger. Ships on USB-C |
| **Operating environment** | Indoor, mains or battery, room temperature. No environmental qualification of any kind has been performed |

**How these figures were obtained.** The envelope and the mass were measured
against the assembled unit, with a tape measure and kitchen scales. Capacity
was not measured, because the mechanism has no point at which it binds: pills
lie loose in one layer and the guides do the singulating, so any single number
would have to be invented in order to be stated.

---

## 5. Measured performance

Every number here was taken on the real board. Where a figure names a count of
trials, that count is the real one.

| Quantity | Value | How it was obtained |
|---|---|---|
| Face recognition, end to end | **209 ms**, identical to the millisecond across **four** captures with different faces and confidences | The invariance is the point: the Neural-ART runtime executes a fixed epoch schedule for a fixed input shape, so cost does not depend on image content |
| Failed capture | 1111 ms | three detector passes plus two 500 ms waits |
| Hand-landmark inference | **285-302 ms** | ST publishes 20.75 ms for this model - an all-internal figure; ~978 KB of our activations sit in PSRAM |
| Pill detector on the NPU | 8-bit integer, decode on the Cortex-M55, **matching its floating-point accuracy** | held-out validation |
| Dispense accuracy | 4 trials: 5/5, 3/3, 3/3, 2/2. All 13 pills counted, by the sensor rather than the motor. A small sample, and the mechanism has miscounted and jammed outside these trials | not a reliability figure |
| Longest *legitimate* detection pulse | **1210 ms** | the number that killed an earlier 1500 ms stall bound, which had left 290 ms of margin before it would have refused a dose that was being delivered correctly |
| Half-step period | 2 ms | smooth and silent under turntable load |
| Battery operation | 1 complete dispense, battery alone, no laptop | standalone boot |
| CPU idle | **~89.6%** in `WFI`; **7-50%** during an intake watch, which is 0.14% of a four-dose day - a daily average of ~87.9% | DWT cycle counts accumulated across the sleep, read out from a task on a 10-second period |

---

## 6. What is on the board and deliberately unused

The board carries more than this build uses. Each one, and why.

| Capability | Why it is unused |
|---|---|
| **Gigabit Ethernet** | Never initialised in this build, and no code path can transmit. Connectivity is planned work; `MEDSIGHT_HANDBOOK.md` section 6.8 |
| **USB data (device and host)** | Only ST-LINK debug and flashing are used. A USB data path would be a route off the device, which is the same argument as Ethernet. |
| **Wi-Fi / BLE** | Not present on the board and nothing is added to the BOM. A carer alert over Wi-Fi and a patient-worn band are the top of the roadmap, and both need a module this hardware does not have. |
| **SAI audio codec and MEMS microphone** | The one event that needs sound is a missed dose, and an active piezo on a GPIO does that for one wire and no code. A codec is neither needed nor in scope. `HAL_SAI_MODULE_ENABLED` is still commented out. |
| **The second XSPI / unused external NOR regions** | The NPU weights occupy four regions; the rest is unclaimed. Documented in `TECHNICAL_REFERENCE.md` section 8 so a future model has somewhere known to go. |
| **Power measurement** | The DK supports instrumented power measurement and **it was never wired up**. The ~89.6% idle figure is a *duty-cycle* measurement from DWT cycle counts, not milliwatts. No power figure in watts is claimed anywhere in this submission, because none was measured. |

---

## 7. The enclosure, stated plainly

**The housing is a prototype shell. It does not lock. There is no tamper
detection.**

This is stated in the hardware document, at this size, because it is a
mechanical property that has a regulatory consequence: residential-care
regulation in most jurisdictions requires medication to be stored **locked**,
and a reader who assumed otherwise would be wrong about where this device can
be deployed today.

The *withholding* is real - the device refuses to release a dose outside its
window, and refuses to release it to a face it does not recognise. **The lock
is not.** Those are different properties, and only one of them is built.

A lockable enclosure, tamper detection and a vibration sensor are the plan for
a complete product. They are future work, in the future tense, and no part of
them is present in the device that ships. `MEDSIGHT_HANDBOOK.md` section 6.4 is the full
argument.

---

## 8. Configuration switches

All are plain macros in the sources. There is **no `.ioc` file** - every
peripheral is configured by hand - so nothing needs regenerating.

| Macro | File | Default | Effect |
|---|---|---|---|
| `MEDSIGHT_PHYSICAL_DISPENSER` | `Inc/dispenser.h` | `1` | `0` runs everything except the physical dispense with **no dispensing hardware attached**, shown on screen instead. A supported configuration, not a debug path, and run on the assembled board. Use it if the mechanism is damaged or missing |
| `MEDSIGHT_ACTION_RECOGNITION` | `Inc/ai/intake.h` | `1` | `0` removes the intake pipeline entirely - verified to drop **every** `stai_pill*` symbol from the ELF. Also the AGPL-free configuration; see `LICENSING.md` section 3 |
| `MEDSIGHT_INTAKE_SIMPLE` | `Inc/ai/intake.h` | `1` | `0` restores the full guarded intake state machine. See `MEDSIGHT_HANDBOOK.md` section 4.7 for why the default is `1` |
| `MS_COIL_PINSET` | `Src/dispenser.c` | `1` | `1` = `D3/D5/D6/D9`. `0` selects an alternative coil pin set |
| `MS_DISPENSE_DIRECTION` | `Src/dispenser.c` | `(-1)` | The turntable turns **anticlockwise** to dispense. `1` is clockwise. Flips the dispensing rotation and the settle-back together, which must always oppose each other |
| `MS_NO_PILL_TIMEOUT_MS` | `Src/dispenser.c` | `25000` | How long with no counted pill before JAM or SHORT |
| `MEDSIGHT_BUZZER_KEYBOARD_CLICK` | `Inc/buzzer.h` | `0` | `1` ticks on every keypress. Off because a device that beeps on every tap is tiring to use |
| `MEDSIGHT_FAST_CLOCK` | build config | Debug `1`, Release `0` | Compresses a day into 24 minutes - one simulated minute per real second |

---

## 9. Power path

One 5 V source, one ground.

**Before any of it: the power-source jumper.** On the underside of the board is
a jumper selecting where the board takes its power from, with positions `VIN`,
`USB-C` and `STLK`. It must be on **USB-C** to run from the battery, and on
**STLK** to build and flash over the debugger. It ships on USB-C.

It is worth stating plainly because the failure it causes is silent: on the
wrong position the board draws nothing, the screen stays dark, and there is no
message to read. That looks like a dead board and it is a jumper.

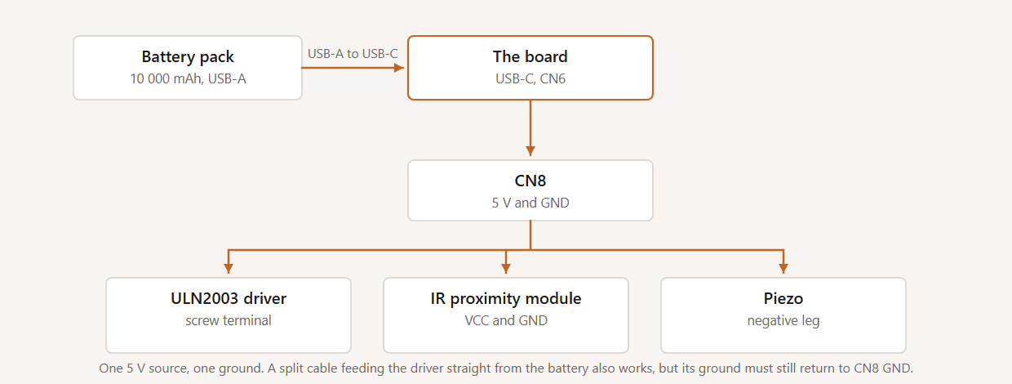
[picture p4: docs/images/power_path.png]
The power path: the battery reaches the board over USB-C, and the driver, the infrared module and the piezo all take 5 V and ground from the board's own CN8 header


Running the ULN2003 from the board's own CN8 `5V` was tested and works
flawlessly, including under motor load. That is the recommended arrangement
because it makes a shared ground structural rather than something you have to
remember.

A split USB cable feeding the ULN2003 straight from the battery pack also works
- but **its ground must still return to CN8 `GND`**. A driver whose ground
floats relative to the MCU will not switch, and the failure looks exactly like
a dead driver: no LEDs, no motion, no error.

For standalone operation set **BOOT1 (SW1) LOW** so the board boots the signed
image from external flash instead of waiting for a debugger. The handbook's
build section covers how that image is signed and flashed.

---

---

## 10. Bring-up order, if you are wiring from scratch

Run in this order. Each step is independently observable, so a failure tells
you which of the eleven wires to look at.

1. **Power only.** Board boots to the MedSight UI. No peripheral wired yet.
2. **Buzzer.** Wire `D10` and `GND`. Tapping the keypad should tick.
3. **IR module.** Wire `OUT`/`VCC`/`GND`. The module's own LED changes state
   when you pass a finger in front of it. The line idles HIGH and pulls LOW
   while broken; real pill breaks measure **17-46 ms**, and anything under
   8 ms is discarded as contact chatter.
4. **ULN2003, no motor.** Wire `IN1`-`IN4` and power. Start a dispense - the
   four channel LEDs should chase in sequence. If they do not light at all,
   go to section 6 and to the ground note in section 4.
5. **Motor.** Plug in the JST. The turntable turns **anticlockwise**, the
   direction that feeds the chute. A differently-handed turntable needs
   `MS_DISPENSE_DIRECTION` changed rather than the coils rewired: it flips
   the dispensing rotation and the settle-back together, which must always
   oppose each other.
6. **Full dispense.** Register a patient, request a dose, watch the on-screen
   progress bar step once per counted pill.

A dispense that counts nothing for 25 seconds reports **JAM** (nothing was
released). One that counts some but not all of the requested pills and then
goes quiet for 25 seconds reports **SHORT** - the turntable needs refilling.
Neither is an error condition and neither calls `Error_Handler()`; both are
normal outcomes of a mechanical device and are recorded in the audit log with
the count that was actually delivered.

---

---

## See also

| Document | What it is |
|---|---|
| `HARDWARE_SPEC.md` section 3 | the pin budget and the reasoning behind it |
| `HARDWARE_SPEC.md` section 2.3 | the turntable and guide geometry, and the stacked-module design intent |
| [`TECHNICAL_REFERENCE.md`](TECHNICAL_REFERENCE.md) | Part C: where every byte on the part lives |
| [`MEDSIGHT_HANDBOOK.md`](MEDSIGHT_HANDBOOK.md) | the device, how to run it, and what comes next |

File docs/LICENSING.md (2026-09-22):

# Licensing

## Is this open source?

**Yes.** MedSight's own code, documentation and CAD are **Apache-2.0**. Read,
build, change, redistribute and sell, keeping the copyright notice and stating
what was changed.

## The repository is multi-licensed

Each component carries the licence its own rights holder grants. `LICENSE` at
the repository root says so and points here.

| What | Licence | Open source |
|---|---|---|
| MedSight firmware, documentation, CAD, tools | Apache-2.0 | Yes |
| Pill detector weights and training pipeline | AGPL-3.0 | Yes |
| µT-Kernel 3.0 BSP2 | T-License 2.1 / 2.2 | Yes |
| CMSIS, STM32N6xx device layer | Apache-2.0 | Yes |
| STM32N6xx HAL/LL, board support package | BSD-3-Clause | Yes |
| MediaPipe hand landmark model | Apache-2.0 | Yes |
| FatFs R0.15 | FatFs licence | Yes |
| DejaVu Sans glyph data | Bitstream Vera / DejaVu | Yes |
| **ST Edge AI runtime, ISP library, the two face models** | **ST SLA0044** | **No** |

**SLA0044 is the only component that is not open source.** It is ST's code for
driving their own accelerator and camera, free to redistribute for use on ST
devices, and every STM32 AI project carries it.

## The pill detector and AGPL-3.0

The detector's weights were trained by this project with Ultralytics YOLOv8,
which is AGPL-3.0, and Ultralytics states that models trained with it are
AGPL-3.0 too.

**This project complies with that.** The complete corresponding source is
published in `tools/pill_detector/`: the training script, the dataset identity
and licence, the trained weights, the exported model before and after the head
was cut, and the accelerator build configuration. The network clause never
applies, because the device has no network.

**One incompatibility is real.** AGPL-3.0 and ST's SLA0044 cannot both govern a
single distributed binary, so no linked binary is distributed: the submission
conveys source and the recipient builds it. Setting
`MEDSIGHT_ACTION_RECOGNITION` to 0 is an AGPL-free configuration, verified by
symbol count.

## Per-file map

| Path | Licence |
|---|---|
| `firmware/FSBL/Src/`, `firmware/FSBL/Inc/`, except the AI files below | Apache-2.0 |
| `firmware/FSBL/Src/ai/ai_vision.c`, `intake*.c`, `npu_init.c` | Apache-2.0 |
| `firmware/FSBL/Src/ai/pill.c`, `stai_pill.c`, and the pill weight blob | AGPL-3.0 |
| `firmware/FSBL/Src/ai/hand.c`, `stai_hand.c`, and the hand weight blob | Apache-2.0 |
| `firmware/FSBL/Src/ai/fd.c`, `faceid.c`, `stai_fd.c`, `stai_faceid.c`, and their weight blobs | ST SLA0044 |
| `firmware/FSBL/Src/ai/ll_aton*.c` and the runtime archive | ST SLA0044 |
| `firmware/FSBL/mtk3_bsp2/` | T-License 2.1 / 2.2 |
| `firmware/Drivers/CMSIS/` | Apache-2.0 |
| `firmware/Drivers/STM32N6xx_HAL_Driver/`, `firmware/Drivers/BSP/` | BSD-3-Clause |
| `firmware/Middlewares/ST/STM32_ISP_Library/` | ST SLA0044 |
| `firmware/Middlewares/Third_Party/FatFs/` | FatFs licence |
| `hardware/cad/`, `docs/`, the site, `tools/` except the pill detector | Apache-2.0 |
| `tools/pill_detector/` | AGPL-3.0 |

**Not in this repository:** ST's prebuilt first-stage bootloader, used only for
boot from external flash. It is ST's binary, downloaded from ST directly; the
handbook gives the link and a fingerprint.

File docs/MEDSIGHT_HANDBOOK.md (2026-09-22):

# MedSight

**An offline medication dispenser that recognises the patient by face and counts
every pill physically leaving the turntable.**

TRON Programming Contest 2026 · RTOS Application category
Entry 54916 · Applicant: Dousik Manokaran

Source code and everything else: **github.com/M-DOUSIK/MedSight**

---

What the device is, how it works, how to run it, how to build and flash it,
and the planned work.

| Part | | |
|---|---|---|
| **1** | System overview | the problem, and what the device does about it |
| **2** | The dose sequence | five stages, end to end |
| **3** | The neural networks | four networks on the accelerator, no cloud |
| **4** | RTOS architecture | six tasks, and the kernel primitives in use |
| **5** | Hardware architecture | wiring, printed parts, specifications |
| **6** | Quick start | ninety seconds, no computer |
| **7** | Operation | every screen and every flow |
| **8** | Building and flashing the firmware | ST-LINK, step by step |
| **9** | Troubleshooting | fault diagnosis |
| **10** | Current limitations and planned work | the roadmap |

---

## Part 1. System overview

### The problem

**Between a fifth and a half of older patients do not take their long-term
medication as prescribed.** The range is **21-55%**, from a 2026 systematic
review of older adults facing treatment burden (Amato et al.), and a second
2026 review across **128 studies** searched to the end of 2024 finds the
problem no less stubborn (Scotti et al.). On dispensing data rather than
self-report, an analysis of **42,601 records** for patients over 65 lands in
the same place (Cardona et al., 2025). The familiar line that adherence
averages 50% comes from the WHO's 2003 review; that report established the
baseline and is cited here for that, not as a current measurement.

In residential care it fails differently, and worse. A study of **256 residents
across 55 care homes** found **69.5% had at least one medication error**, at a
mean of 1.9 errors each, with residents taking a mean of 8 medicines. The causes
named were not carelessness: high staff workload, lack of medicines training,
**drug round interruptions**, paper records, and administration systems that are
hard to fill and hard to check.

This is getting larger everywhere. **By 2030 one person in six worldwide
will be 60 or over**, and that population doubles to 2.1 billion by 2050 (World
Health Organization, October 2025). Care work is the constraint on top of it:
the same body projects a shortfall of about **11 million health workers by
2030**, concentrated in low- and lower-middle-income countries.

Most pill organisers are passive. A labelled box does not know who opened it, or
whether anything was taken.

### What the device does

A carer enrols a patient once: their face, their name, how many pills they take
at a time, and up to four times of day. That takes about two minutes and it
happens behind a passcode.

From then on the device runs on its own. It reminds the patient when a dose is
due. It checks who is standing in front of it, by face, using its own neural
processor. It turns a motorised turntable and **counts each pill as it
physically passes an infrared sensor**, so the number on screen is a
measurement rather than an assumption. It runs action recognition over the
confirmation window. And it writes every one of those events to a memory card that a carer
can read back on the device itself.

One device, many patients. Each one is recognised by face and carries their own schedule, up to four dose times a day. One medication per turntable.

### How it differs from existing dispensers

**It counts, rather than assumes.** Any dispenser can turn a motor for a fixed
time and hope the right number of pills came out. This one has a sensor in the
chute, and the progress bar on screen steps once per pill it actually detects.
If three pills come out when four were asked for, the record says three.

**It knows who it is dispensing to.** Face recognition runs entirely on the
board, on a dedicated neural processor, in **209 ms**. Nothing is uploaded and
no photograph is stored: what is kept is a mathematical fingerprint of the face,
not the picture that produced it.

**It runs on its own.** Signed firmware in the board's external flash, its own
battery in the back of the housing, no computer anywhere. It is a device, not a
demo.

**It does not need anyone's servers.** A dispenser with a companion app and an
account necessarily moves the adherence record off the device and onto somebody
else's machine. This build has no radio at all, so the record stays on the card
in the device.

---

## Part 2. The dose sequence

Five steps. The fourth is the one that matters.

| | | |
|---|---|---|
| **1** | **The window opens** | A µT-Kernel alarm handler fires exactly once. The home screen names the patient and the time; three short beeps. |
| **2** | **Identification** | CenterFace detects the face, MobileFaceNet encodes it as a 128-dimension embedding, and it is matched against the enrolled gallery by cosine similarity. **209 ms**, every time. |
| **3** | **Dispense** | The turntable turns. Each pill passes the infrared sensor on its way down the chute. Measured pulse: **17-46 ms**, because pills slide rather than fall. |
| **4** | **Counted, not timed** | The progress bar steps **once per counted pill**. Pill 3 of 6 is a half-full bar reading 50% because three pills were actually counted. |
| **5** | **Confirmation** | Action recognition observes the window. The patient's press of the large green button remains the confirming action. One record goes to the card. |

**Why step 4 is the one that matters.** With the mechanism attached the bar
advances on each sensor pulse, so it reports what the hardware actually did. A
timed animation exists only in the simulation build, where
`MEDSIGHT_PHYSICAL_DISPENSER` is 0 and there is no sensor to read. That is also
why the audit line records the count that actually came out:

```
DISPENSE: <patient> <n> requested, <m> counted (OK)
```

written once, after the outcome is known, so the log never contains two claims
about one event.

**If a dose goes wrong**, neither outcome is treated as a system fault, because
a mechanical device jamming is normal:

- **JAM** - 25 seconds with nothing counted at all. Nothing was released.
- **SHORT** - some pills, then 25 seconds of silence. The turntable needs refilling.

The 25 seconds measures **time since the last counted pill**, so a working
mechanism can take as long as it needs and a stopped one is caught in one
window.

---

## Part 3. The neural networks

Four neural networks run on the board's Neural-ART accelerator. Nothing is sent
anywhere.

| Network | What it decides | Origin |
|---|---|---|
| **CenterFace** | Detects a face and emits five landmarks with it, both mouth corners among them | STMicroelectronics |
| **MobileFaceNet** | Encodes the face crop as a 128-dimension embedding for cosine matching | STMicroelectronics |
| **MediaPipe hand landmarks** | 21 keypoints, giving the fingertip position during the confirmation window | Google, via ST's model zoo. We selected it, quantised it, compiled it to the NPU and integrated it. We did not train it |
| **Pill detector** | Single-class detection in a mouth-centred region. Corroboration only | **Trained by this team** |

The pill detector was trained here on a public pill dataset, exported, and
adapted to the accelerator: the convolutional body runs as 8-bit integer on the
NPU and the YOLO decode runs on the Cortex-M55. It corroborates and does not
decide, because at the deployment distance a pill is about an 8-pixel object
and per-frame detection is around 7%. On the validation set the 8-bit model
matches
the floating-point model it was trained from.

**Everything around the face networks is our code too**: the frame snapshot, the
box decode, the normalisation, the 8-bit quantisation of the fingerprint, the
cosine matching against the gallery, and writing it to the card.

**One measurement worth keeping.** The hand model scores 0.0078 on a face, never
goes above 0.035 across 400 random images, does not fire on an ear waved
deliberately in front of it, and scores about 0.50 on a hand at the mouth. Four
rounds of simpler skin-colour heuristics could not separate a moving ear from a
hand; a model that knows what a hand is settled it in one step.

---

## Part 4. RTOS architecture

This is entered in the RTOS Application category, judged on real-time
performance, power saving and memory footprint. The answer is not "we used an
RTOS".

| | |
|---|---|
| **89.6%** | of wall-clock time asleep in `WFI`, waking about 980 times a second |
| **85.6% / 63.0%** | of the code and data regions used, leaving 147 KB and 378 KB free |

### Kernel primitives in use

| Primitive | What it does here |
|---|---|
| `tk_cre_tsk` | **Six tasks**, priorities derived rate-monotonically: shortest period gets the highest priority, each number justified in writing. The AI task sits *below* the interface deliberately, which is what keeps touch and the physical button alive while the accelerator works |
| `tk_cre_flg`, `tk_wai_flg` | **Inference is dispatched through an event flag.** The interface's wait has three outcomes to tell apart in one blocking call: face found, no face, or the AI task never answered. A queue, a semaphore or a mutex cannot say that. The payoff is behavioural: the interface used to freeze inside the neural processor for seconds |
| `tk_cre_alm`, `tk_sta_alm` | **Dose scheduling is an alarm handler**, not a task polling the clock. Polling would wake 8,640 times a day in order to act four times, and would spend the power figure above doing it. The handler sets one bit and returns; every line of real work happens in a task |
| `tk_cre_mbf`, `tk_cre_mtx` | The logger's queue, so no caller ever waits on an SD write, and the firmware's one mutex: the clock, which has two readers |
| `low_pow()` | The vendored board support package ships its idle hook **empty**. Ours executes `WFI` and accounts for the cycles, which is where the 89.6% comes from |

**One file talks to the kernel.** Every call above lives in `ms_osal.c`, behind
an abstraction the rest of the firmware was written against, so the kernel's use
is deliberate and in one place rather than scattered. The vendored kernel itself
is unmodified except for six files out of about 230, none of which implements a
system call.

**Two idioms were evaluated and deliberately not adopted**, with the reasoning
written down: a fixed-size memory pool, because this firmware has no fixed-size
runtime allocation site at all and adopting one would have meant inventing an
allocation in order to have something to pool; and an event flag for the confirm
state, because all three of its conditions are produced by the task that would
wait on them. Neither would have done any work.

---

## Part 5. Hardware architecture

### Wiring and interconnects

How the peripherals connect

**Eleven jumper wires**, plus the motor's own keyed 5-pin plug into the driver
board. No resistors, no transistors, no level shifters, no external regulator.

| Wire | Board label | MCU pin | To |
|---|---|---|---|
| 1 | `D3` | PE9 | ULN2003 `IN1` (coil A) |
| 2 | `D5` | PE10 | ULN2003 `IN2` (coil B) |
| 3 | `D6` | PE13 | ULN2003 `IN3` (coil C) |
| 4 | `D9` | PE14 | ULN2003 `IN4` (coil D) |
| 5 | `5V` (CN8) | - | ULN2003 terminal `+` |
| 6 | `GND` (CN8) | - | ULN2003 terminal `-` |
| 7 | `D2` | PD0 | IR module `OUT` (interrupt, both edges) |
| 8 | `5V` (CN8) | - | IR module `VCC` |
| 9 | `GND` (CN8) | - | IR module `GND` |
| 10 | `D10` | PA3 | piezo `+` |
| 11 | `GND` (CN8) | - | piezo `-` |

**Wire by the silkscreen label** printed on the board, not by the colour in the
drawing. The colours above are that drawing's own convention.

`D14` and `D15` are the camera's I2C and must stay clear.

### Power

One 5 V source, one ground.

The power path: the battery reaches the board over USB-C, and the driver, the infrared module and the piezo all take 5 V and ground from the board's own CN8 header

Running the driver from the board's own `CN8 5V` was tested under motor load and
is the recommended arrangement, because it makes a shared ground structural
rather than something you have to remember. A split USB cable feeding the driver
straight from the battery pack works too, **but its ground must still return to
CN8 `GND`** - a driver whose ground floats will not switch, and it looks exactly
like a dead driver.

### The printed parts

The three printed parts, rendered from their STL files with numbered callouts

*Rendered from the STL files that go to the printer. The callout numbers are:*

| | |
|---|---|
| **01 Board enclosure** | 1 housing shell, 2 port and connector grid, 3 battery compartment, 4 MedSight brand plate |
| **02 Pill dispenser** | 1 enclosure box, 2 rotating carousel, 3 central drive motor hub, 4 dispensing chute, 5 output collection drawer, 6 side sensor brackets, 7 internal divider wall |
| **03 Structural pillars** | 1 structural pillar, eight off |

| Part | Size |
|---|---|
| Board enclosure | **164 x 153 x 152 mm** - sloped front face, rear battery compartment |
| Pill dispenser | **179 x 92 x 50 mm** - carousel, motor hub, chute, collection drawer, sensor brackets |
| Structural pillars, 8 off | **180 x 100 x 10 mm** |

**The chute geometry is what makes the counter work.** Pills slide rather than
free-fall, which is why detection pulses measure 17-46 ms instead of the few
milliseconds a drop would give. A driver sized for a free-fall would have thrown
away every real pill.

**One sensor, and a threshold set from measurement.** The module is a
reflective infrared proximity sensor: a pill passing in front of it returns
enough light to pull the output low, and the output is digital, so the
in-or-out decision is made in the sensor rather than in software. What that
costs is honest to state: how strongly a pill returns light depends on its
colour and finish, which is why the discrimination floor was set from measured
pulse durations rather than assumed.

### Specifications

| | |
|---|---|
| **Processor** | Arm Cortex-M55 at 800 MHz, STM32N657X0H3Q |
| **AI accelerator** | ST Neural-ART at 1 GHz, about 600 GOPS |
| **Networks on it** | 4 |
| **Memory** | ~4.2 MB on-chip SRAM · 1 Gbit external NOR for weights · 256 Mbit PSRAM |
| **Firmware size** | 85.6% of the code region, 63.0% of the data region |
| **RTOS** | µT-Kernel 3.0, six tasks |
| **CPU idle** | ~89.6% in `WFI` |
| **Display** | 5 inch, 800 x 480, capacitive touch |
| **Camera** | Sony IMX335 |
| **Storage** | microSD. The only storage in the device |
| **Clock** | internal RTC, kept across resets in the backup domain |
| **Actuator** | 28BYJ-48 stepper, half-step, 2 ms per step |
| **Pill sensor** | infrared proximity, both edges, 8 ms discrimination floor |
| **Audio** | active piezo, five patterns |
| **Power** | 5 V USB-C. Runs on its own battery, with no mains supply and no computer |
| **Capacity** | multiple patients, 4 dose times each, 1-10 pills per dose, 1 turntable. The gallery size is a build constant, `MAX_PATIENTS`, set to 10 in this build |

### Measured performance

| | |
|---|---|
| Face recognition, end to end | **209 ms**, identical to the millisecond across four captures |
| Hand-landmark inference | 285-302 ms |
| Pill detector, quantisation | 8-bit matches floating point on the validation set. At the deployment distance, per-frame detection is about 7% |
| **Dispense accuracy** | 4 trials: 5/5, 3/3, 3/3, 2/2. All 13 pills counted. A small sample, not a reliability figure: the mechanism has miscounted and jammed outside these trials |
| Longest legitimate detection pulse | 1210 ms |
| Battery operation | one complete dispense on battery, no laptop |

The 209 ms is the same on every capture: four faces, four detector
confidences, one timing. The accelerator runs a fixed schedule for a fixed
input size, so the cost does not depend on the picture.

---

## Part 6. Quick start

**No computer. About ninety seconds.**

If the dispensing hardware is damaged or missing, skip to 8.9: the whole
application runs without it, with the dispense shown on screen.

1. **Check the two settings on the board.** Both ship correct and neither
   needs a tool:
   - `SW1 (BOOT1)` must be **LOW**.
   - The **power-source jumper on the underside of the board** must be on
     **USB-C**, not `STLK` and not `VIN`. This is the one that catches people:
     on `STLK` the board takes its power from the debugger, so the battery
     does nothing and the device looks dead.
2. **Check the battery cable is connected.** The cable lives inside the
   housing and is normally left plugged in: USB-C into `CN6` on the board, the
   other end into the battery in the rear compartment. If it has come loose,
   connect it.
3. **Press the power button on the back.** It is the battery's own button,
   brought out through the back panel, and it glows while the battery is
   supplying power. **One press turns the device on. Two presses in quick
   succession turn it off.**

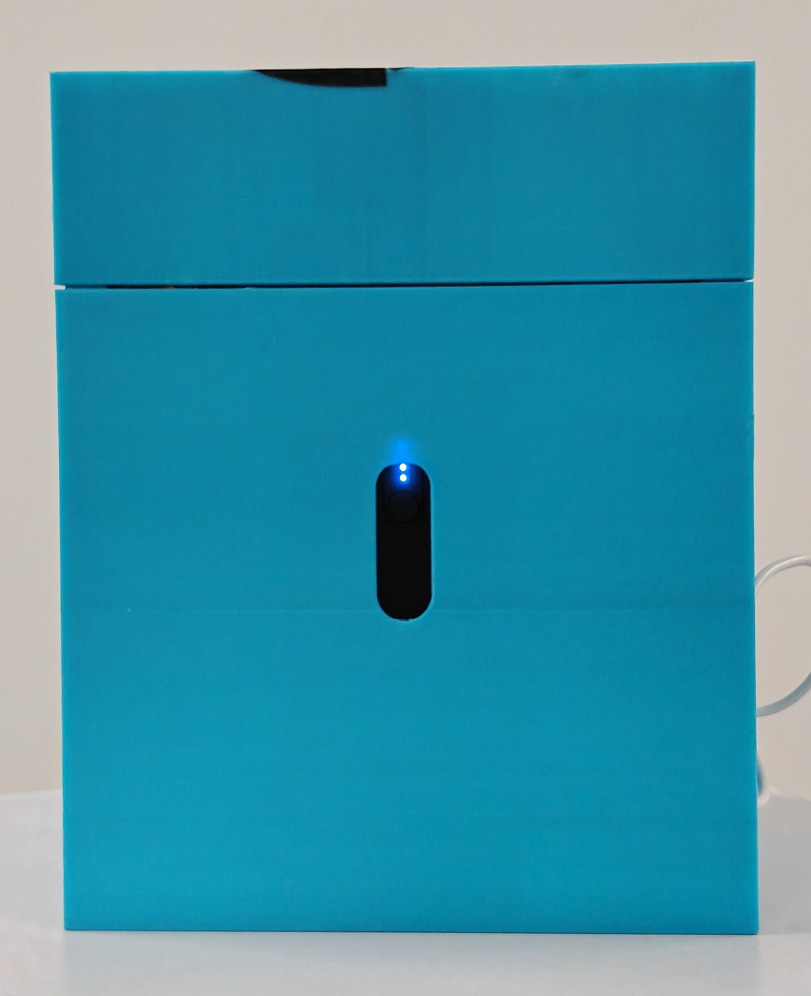
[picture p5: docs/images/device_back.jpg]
The back panel of the device, a plain face with the illuminated power button at its centre
   

   *The back of the device. The button is the only control on this face.*

4. Wait about ten seconds. The home screen appears: a teal bar reading
   **SMART PILL DISPENSER**, two large buttons, and an animated cat.
5. Tap the amber **DISPENSE PILLS**, then **I AM READY**.
6. **Look at the camera.** A live preview, then the screen goes flat pink for
   about three quarters of a second. **That pause is the neural processor
   running and it is deliberate** - its working memory overlaps the display
   buffer, so the screen is switched off rather than left showing raw tensor
   data. It is a pause, not a fault.
7. The device greets the patient **by name** and shows the exact image it ran
   on, with the detector's box and five landmarks drawn on it. Tap **NEXT**.
8. **Watch the dispense.** The turntable turns, each pill passes the sensor,
   and the bar steps once per counted pill. Two short beeps on success.

**The unit as shipped has no memory card fitted.** The card is supplied in the
packet with the pills. Its slot is on the board, inside the housing, so fitting
it means opening the enclosure. Until it is fitted the home screen says so in
those words: *No SD card - doses are not being recorded. The device still works
normally.* Everything described in this handbook runs without it. What does not
survive a power cycle is the enrolled gallery, the dose history, and any change
to the carer passcode; fit the card and all three persist.

**Two LEDs tell you the RTOS is alive.** The green one toggles once per
iteration of the 1 ms camera task, so at about 500 Hz your eye reads it as a
steady dim glow. The red one toggles every 500 ms in the idle task, a 1 Hz
blink. Both ends of the priority range, visibly running, on battery.

---

## Part 7. Operation

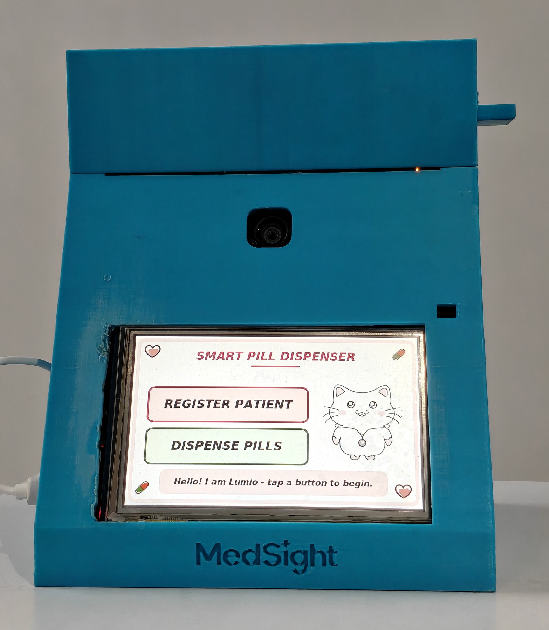
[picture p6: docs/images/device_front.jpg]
The device straight on, the 5 inch screen showing the home screen with its two large buttons and the mascot, the camera above the screen and the collection drawer below


*Everything in this part happens on this screen. The camera is the small lens
above it; the dose arrives in the drawer below.*

### 7.1 Carer mode

**The passcode is `1234`.** It is a build-time default, the device says on every
boot that it is still on the default, and it can be changed.

**To get in:** tap the **title bar**, the coloured strip across the top of the
home screen, **five times within three seconds**, then type the passcode.

The title bar is the target because it is the one thing on that screen that is
unmistakably not a button, so nobody taps it five times by accident. Any tap
elsewhere resets the count.

### 7.2 A ten-minute evaluation

| # | Step | How | Expected |
|---|---|---|---|
| 1 | Power on | battery pack to `CN6` | home screen |
| 2 | Enter carer mode | title bar x5 in 3 s, then `1234` | **CARER MODE** menu |
| 3 | Set the clock | `SET CLOCK`, twelve digits `DDMMYYYYHHMM`, `OK` | "Clock set." |
| 4 | Leave carer mode | `EXIT` | home screen, schedule armed |
| 5 | Register a patient | `REGISTER PATIENT`, `1234`, `I AM READY`, type a name, `DONE`, face the camera, `NEXT`, set pills per dose, `NEXT`, `CONFIRM` | "Registered!" |
| 6 | Set a schedule | carer mode, `PATIENTS`, the name, `DOSE TIMES`, tap a slot, four digits, `OK`, `SAVE` | "Dose times saved." |
| 7 | Dispense | home, `DISPENSE PILLS`, `I AM READY`, face the camera, `NEXT` | greeted by name; bar steps per pill; two beeps |
| 8 | Confirm | the large green **I TOOK IT!** | "THANK YOU!" |
| 9 | Read the log back **on the device** | carer mode, `REVIEW LOG` | the last few lines. **Missed doses are the one line that is not grey** |

**Step 5 is worth watching for one detail.** The passcode is asked **before the
camera is ever used**. Asking afterwards would mean a face and a name had
already been taken from somebody who was never authorised to give them.

### 7.3 Registering somebody

`REGISTER PATIENT`, passcode, `I AM READY`, type the name, `DONE`, the person
looks at the camera, `NEXT`, set the pill count, `NEXT`, `CONFIRM`.

The name is asked **before** the photograph on purpose: being photographed by a
machine that has not yet asked who you are is the wrong way round.

**Enrol in the light the device will be used in.** This is the single most
useful thing you can do. One test round measured match scores of **57 to 88 for
the same person** under varying illumination, rejecting them about one time in
three. That is a property of one-shot face recognition, not a fault, and the
retry screen rescued every case - but a demo filmed in different light from the
enrolment will show that retry screen.

### 7.4 The clock

**Set it first on a new device.** The device has no network, so it cannot set
its own clock, and a wrong clock gives doses at the wrong time with an audit
trail that says it was right.

Carer mode, `SET CLOCK`, twelve digits: day, month, year, hour, minute. For
7 March 2027 at 08:30, type `070320270830`. An impossible entry names the field
that is wrong rather than just saying invalid.

### 7.5 Dose times and dose size

**Dose times:** carer mode, `PATIENTS`, the name, `DOSE TIMES`. Four slots. Tap
one, type four digits, `OK`, `SAVE`.

**Dose size:** carer mode, `PATIENTS`, the name, `DOSE SIZE`, `-` and `+`, one
to ten, `SAVE`. This is how many pills at once, not how many are in the machine.

### 7.6 Refilling

The turntable is open from above. Lay pills loose on it. They do not need
arranging: the guides singulate them as the disc turns.

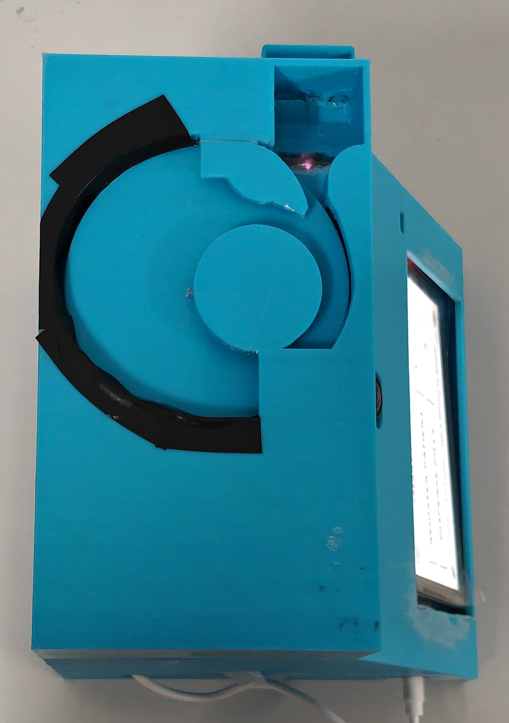
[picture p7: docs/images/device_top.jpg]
Looking straight down at the open turntable well: the disc with a curved black guide wrapping its perimeter, the drive hub at its centre, and the chute and infrared sensor at the top right


*The turntable, from above. Pills lie in a single layer and the guide feeds
them to the chute one at a time.*

**The device does not track how many pills are on the turntable**, and that is
a decision rather than an oversight: it has no way to know when a carer tops it
up, so rather than keep a number that would quietly go wrong, it keeps none. So
**check the turntable on a routine, not when the device asks.**

**If it jams or loses power, open the housing and take the dose out by hand.**
The case does not lock and nothing holds the pills in. A machine must never
stand between somebody and their medication.

### 7.7 The dose history

Carer mode, `REVIEW LOG`.

| Line | Meaning |
|---|---|
| **DISPENSE** | pills came out, and how many were counted |
| **CONFIRMED** | the patient pressed I TOOK IT |
| **SKIPPED** | the patient pressed Skip |
| **MISSED** | a window opened and closed with nothing dispensed |

Missed doses are shown in colour; everything else is grey.

### 7.8 Audio patterns

| Sound | Meaning | For |
|---|---|---|
| One very short blip | you tapped something | whoever is tapping |
| **Two short beeps** | the dose came out correctly | the patient |
| **Four quick short beeps** | jam, or the turntable is empty | whoever is there |
| **Three pairs of short beeps** | pills are due now | the patient |
| **Four long beeps, twice** | **a dose was missed** | **the carer** |

**Only the missed-dose alert uses long tones, and that is deliberate.** The
reminder is polite because it fires on schedule when nothing is wrong. The
missed-dose alert is insistent because by then something is, and it is aimed at
a **carer**, not the patient: somebody who has already not responded to a
reminder does not need to be beeped at harder. The long beeps exist to bring a
carer to the device.

### 7.9 Removing somebody

Carer mode, `PATIENTS`, the name, `DELETE`, `DELETE` again.

This removes their name **and** their face data together. A partial delete would
defeat the point: a record with a cleared name and a live fingerprint still
matches a face, it just matches it to nobody.

**The confirmation screen times out to KEEP.** Every other timeout in this
interface goes forward; this one goes back, because that is the only correct
default for something you cannot undo.

### 7.10 The camera during the confirm screen

The camera runs for up to 30 seconds on the **TAKE YOUR PILL NOW** screen,
looking for a hand going to the mouth.

**No picture is ever saved**, to the card or anywhere else. What survives is a
few words in the history.

Nothing on screen announces this, deliberately: a warning on the one screen
where somebody is being asked to do something simple risks distracting them
from doing it. **A person being watched by a camera should still be told, so
tell the patient and their family.**

---

## Part 8. Building and flashing the firmware

Every command here was actually run.

**What you are building.** This firmware starts from ST's STM32N6 example
application and replaces its core. µT-Kernel 3.0 is the RTOS, reached through
an abstraction layer written for this project; six vendored kernel files differ
from upstream and every file implementing a system call is byte-identical. The
OS abstraction layer, the 22-screen user interface and its design system, the
state machine, carer mode, the scheduler and time source, the SD logger and the
block-device layer beneath FatFs, the dispenser driver and the alert path are
original MedSight code. Four neural networks were selected, quantised, compiled
to the accelerator and integrated. Every third-party component, its rights
holder and its licence are inventoried in
[`THIRD_PARTY_SOFTWARE.md`](THIRD_PARTY_SOFTWARE.md).

### 8.1 What you need

**STM32CubeIDE 2.1.1** or newer. **There is no `.ioc` file**: every peripheral
is configured in code rather than generated, so there is nothing to
regenerate.

`STM32_Programmer_CLI` and `STM32_SigningTool_CLI` ship inside CubeIDE, with the
external loader `MX66UW1G45G_STM32N6570-DK.stldr` beside them. Set these once
per PowerShell session:

```powershell
$BIN    = "C:\ST\STM32CubeIDE_2.1.1\STM32CubeIDE\plugins\com.st.stm32cube.ide.mcu.externaltools.cubeprogrammer.win32_2.2.500.202603051304\tools\bin"
$CLI    = "$BIN\STM32_Programmer_CLI.exe"
$SIGN   = "$BIN\STM32_SigningTool_CLI.exe"
$LOADER = "$BIN\ExternalLoader\MX66UW1G45G_STM32N6570-DK.stldr"
```

Your plugin folder's version suffix will differ. `dir "$BIN\.."` to find it.

### 8.2 The one rule for external-loader operations

> **After any external-loader operation, unplug the USB cable.**
>
> Not a reset. Not the IDE's stop button. The cable, out, for a few seconds.

Back-to-back operations through the external loader leave the flash chip's bus
state confused. The symptom is a boot that hangs where the external flash is
first touched: the log stops right after `ai_vision_init: DEBUG build (-O0).`
and the screen holds a stale frame. **The flash contents are fine**; only the
peripheral's bus state needs clearing.

**This applies to reads as well as writes.** A verification read leaves the bus
in the same state a write does, and a read is exactly when it is most tempting
to leave the board running.

### 8.3 Boot switches

| Mode | SW1 (BOOT1) | SW2 (BOOT0) | |
|---|---|---|---|
| **A, development** | **HIGH** | LOW | waits for the debugger, gives you the log |
| **B, standalone** | **LOW** | LOW | runs from external flash, no computer |

Mode A is the factory position and is enough to evaluate every software feature.

### 8.4 Build

Import `firmware/STM32CubeIDE/FSBL` and build **Debug**. Expect **0 errors, 0
warnings**.

Headless:

```powershell
& "C:\ST\STM32CubeIDE_2.1.1\STM32CubeIDE\stm32cubeidec.exe" --launcher.suppressErrors -nosplash `
  -application org.eclipse.cdt.managedbuilder.core.headlessbuild `
  -data <a scratch workspace dir> `
  -import "firmware\STM32CubeIDE\FSBL" `
  -cleanBuild "MedSight_FSBL/Debug"
```

On Windows the `-import` path **must use backslashes**; a forward-slash path
with a drive letter is parsed as a URI scheme and fails.

### 8.5 Flash the neural network weights

**The firmware does not contain its neural network weights.** The linker marks
those external flash regions as not-to-be-loaded, deliberately, so building and
flashing the application never writes them.

A fresh clone therefore compiles a perfectly good binary, flashes it, and
produces a device whose face recognition and pill detection **both output
nonsense, with nothing in any log to say why.**

Five images, once per board:

```powershell
& $CLI -c port=SWD mode=UR -el $LOADER -w "weights\fd_data.xSPI2.bin"       0x70380000
& $CLI -c port=SWD mode=UR -el $LOADER -w "weights\ec_blobs.xSPI2.bin"      0x71000000
& $CLI -c port=SWD mode=UR -el $LOADER -w "weights\faceid_data.xSPI2.bin"   0x72000000
& $CLI -c port=SWD mode=UR -el $LOADER -w "weights\hand_atonbuf.xSPI2.bin"  0x73000000
& $CLI -c port=SWD mode=UR -el $LOADER -w "weights\pill_atonbuf.xSPI2.bin"  0x73400000
```

**Then unplug the cable** (see 8.2).

| Region | Address | What |
|---|---|---|
| `fd_data` | `0x70380000` | face detector weights |
| `ec_blobs` | `0x71000000` | accelerator microcode |
| `faceid_data` | `0x72000000` | face embedder weights |
| `hand_atonbuf` | `0x73000000` | hand landmark model |
| `pill_atonbuf` | `0x73400000` | the pill detector we trained |

SHA-256 prefixes for all five are in `weights/README.md`, so a mis-copied file
is caught before it becomes a debugging session.

**Use `mode=UR`, not `mode=HOTPLUG`.** HOTPLUG needs a live, responsive core,
and with MedSight running the erase fails outright, because the application has
the external flash memory-mapped while the loader wants the same bus in indirect
mode.

### 8.6 Flash the application

**Move the power-source jumper on the underside of the board to `STLK` first**,
so the board is powered by the debugger while it is being programmed. Move it
back to **USB-C** before running on the battery. It is the same jumper the
quick start mentions, and it is the usual reason a flash or a standalone boot
fails for no visible cause.

In the IDE, press **Run**. The launch configuration is committed and needs no
editing. From a terminal instead:

```powershell
& $CLI -c port=SWD -w "firmware\STM32CubeIDE\FSBL\Debug\MedSight_FSBL.elf" -rst
```

**Use `-rst`, a software reset.** An explicit go-to-address was tried and did
not reliably produce a running application on this board. This command never
touches external flash, so it is the fast every-edit loop.

### 8.7 Watch the log

ST-LINK virtual COM port, **115200 8N1**. A correct boot says, in order:

```
ai_vision_init: face detector + embedder ready.
ARENA SELFTEST PASS: 225280 bytes writable and readable
intake: hand landmark model ready (MediaPipe 224x224 INT8, 21 keypoints, ...)
intake: pill detector ready (YOLOv8n 160x160 INT8, head cut, decode on CPU).
dispenser: ...
buzzer: active piezo on PA3 (Arduino D10), keyboard click off
task_camera_isp: started.
```

**If detection runs but the numbers are meaningless, suspect a weight region
before you suspect the code.** A missing or wrong weight image does not announce
itself as an error: the network initialises cleanly and returns nonsense.

### 8.8 Standalone boot

**Why it takes two stages.** The STM32N6 has **no internal flash**. Its boot ROM
copies a first-stage loader from external flash into RAM, and that copy is
**capped at 512 KB**. MedSight is about 880 KB, so it can never *be* the first
stage.

| Stage | What | Address |
|---|---|---|
| 1 | ST's prebuilt loader (`ai_fsbl.hex`) | `0x70000000` |
| 2 | MedSight, signed as second stage | `0x70100000` |
| - | Neural network weights, untouched | `0x70380000`+ |

**Get ST's loader.** It is **not in this repository** because it is ST's binary,
not ours. Download **X-CUBE-N6-AI-POWER-MEASUREMENT** v1.4.0 or newer and take
`FSBL/ai_fsbl.hex`. The copy verified against:

```
sha256  8fa77dcdcb9aeed6e167c1ce5ffe9e16071fdeced8d13e22edd31a37abed1993
size    176,541 bytes
```

**Sign the application.** From `firmware/STM32CubeIDE/FSBL`:

```powershell
Remove-Item -Force "Debug\MedSight_ssbl.bin" -ErrorAction SilentlyContinue
& $SIGN -bin "Debug\MedSight_FSBL.bin" -nk -t ssbl -hv 2.3 -la 0x34000000 -align -o "Debug\MedSight_ssbl.bin"
```

| Flag | Why |
|---|---|
| `-t ssbl` | **second** stage. `-t fsbl` produces an image the ROM can never load, because of the 512 KB cap. Getting this wrong costs an afternoon, so it is worth checking twice |
| `-hv 2.3` | the boot header version the ROM expects |
| `-la 0x34000000` | load address, must match the linker script |
| `-nk` | no signing key; the board is not in a secured state |
| `-align` | pad to the alignment the loader requires |

**Flash both stages:**

```powershell
& $CLI -c port=SWD mode=UR -el $LOADER -w "<path>\ai_fsbl.hex"
& $CLI -c port=SWD mode=UR -el $LOADER -w "Debug\MedSight_ssbl.bin" 0x70100000 -v
```

**Use `-v`. Verify the whole file.** Do not check a few bytes of a magic number
and call it confirmed: during bring-up that produced a "verified" write that had
not happened, because both candidate images shared those bytes.

**Then unplug the cable**, set **SW1 LOW**, and power it from anything 5 V. To
get back to Mode A, set SW1 HIGH; nothing is erased.

### 8.9 Running with no dispensing hardware

Fully supported, and it is how a reviewer without a stepper motor should build
this. In `firmware/FSBL/Inc/dispenser.h`:

```c
#define MEDSIGHT_PHYSICAL_DISPENSER 0
```

Rebuild. Everything except the physical dispense still runs - face
recognition, scheduling, carer mode, the audit log, all 22 screens - and the
dispense itself is shown on screen instead of turned by a motor.

Both values build with 0 errors and 0 warnings, and the no-hardware branch is
the earlier on-screen dispense kept byte-for-byte. It has been run on the
assembled board, not merely compiled, and it is the configuration to use if
the mechanism is unavailable.

### 8.10 Other switches

| Macro | File | Default | Effect |
|---|---|---|---|
| `MEDSIGHT_PHYSICAL_DISPENSER` | `Inc/dispenser.h` | `1` | `0` = no hardware needed |
| `MEDSIGHT_ACTION_RECOGNITION` | `Inc/ai/intake.h` | `1` | `0` removes the intake pipeline entirely |
| `MEDSIGHT_INTAKE_SIMPLE` | `Inc/ai/intake.h` | `1` | `0` restores the full guarded intake state machine |
| `MS_COIL_PINSET` | `Src/dispenser.c` | `1` | `0` selects an alternative coil pin set |
| `MS_DISPENSE_DIRECTION` | `Src/dispenser.c` | `(-1)` | Anticlockwise. `1` reverses it |
| `MS_NO_PILL_TIMEOUT_MS` | `Src/dispenser.c` | `25000` | how long with no counted pill before JAM or SHORT |
| `MEDSIGHT_FAST_CLOCK` | build config | Debug `1` | compresses a day into 24 minutes, so a dose window lasts 30 real seconds |

**Demo mode is worth knowing about.** With `MEDSIGHT_FAST_CLOCK`, one simulated
minute is one real second, so a window opening, being met, and a later one being
missed all fit in one sitting. Release is the honest wall-clock build, and
nothing above the time source knows which is behind it.

---

## Part 9. Troubleshooting

### Device messages

| The screen says | What happened | What to do |
|---|---|---|
| **JAM** | 25 s with nothing counted. Nothing was released | Open the housing, check the turntable and chute. Give the dose by hand |
| **NOT ENOUGH PILLS** | Some pills, then 25 s of nothing | Refill the turntable. **Check how many the patient actually got**: the log records what really came out |
| **No memory card** | Card missing or not seated | Power off, reseat, power on. Nothing is recorded while this shows |
| **The clock has never been set** | Exactly that | See 7.4. Doses cannot be scheduled until it is set |
| **FACE NOT RECOGNISED** | The match failed | TRY AGAIN, better light, face straight on. Re-enrol in the room's own light if it persists |
| **Gallery full** | Ten already registered | Delete somebody |
| Nothing on screen, **red LED blinking about twice a second** | A startup fault. The board never reached the home screen | Most often the **camera or LCD ribbon is not seated**. Power off, reseat both, power on. See the lights table below |
| Nothing on screen | No power | Check the cable and the battery. Then check the **power-source jumper on the underside of the board**: it must be on **USB-C** to run from the battery, and on **STLK** to run from the debugger. A board on the wrong one is silent and looks broken |
| The turntable never moves, or the mechanism is damaged | The dispensing hardware is not working | **The device does not need it.** Rebuild with `MEDSIGHT_PHYSICAL_DISPENSER 0` and the whole application runs with the dispense shown on screen instead. See 8.9 |

**If the dispensing hardware is damaged or missing, nothing is lost.** One
macro and one rebuild runs the device without it, and 8.9 is the whole
procedure.

**A known intermittent, stated rather than hidden:** the memory card
occasionally fails to initialise at boot and recovers on its own. If the device
starts up saying nobody is registered, power off, reseat the card, power on. The
patients are still on it.

### Board LEDs

Two LEDs on the board say what the firmware is doing, and one of them means
the opposite of what people assume. **Blinking red is not always a fault: the
rate is the message.**

| Light | What it looks like | What it means |
|---|---|---|
| Red | **Twice a second**, evenly, forever | **A startup fault.** The board stopped before the scheduler started, so nothing else is running. Almost always the camera or the LCD ribbon not seated |
| Red | **Once a second** | **Normal.** The lowest-priority task is running, which means the whole system is scheduling correctly. This is the light you want |
| Red | Fast flicker | The camera pipeline is reporting errors while running |
| Green | Steady or fast flicker | The camera pipeline is alive and processing frames |

**The camera is not optional.** Unlike the dispensing hardware, which the
device runs without (8.9), camera bring-up is part of mandatory
startup: if the sensor does not answer, the firmware stops in its fault
handler and blinks red. A device that blinks twice a second and shows
nothing has almost certainly had a ribbon shaken loose.

### During flashing

| Symptom | Cause | Fix |
|---|---|---|
| Boot log stops after `ai_vision_init`, screen frozen | flash bus state after a loader operation | **unplug the cable** (8.2) |
| Networks initialise, outputs are nonsense | weights missing or at the wrong address | 8.5 |
| HOTPLUG connection or erase fails | MedSight is running and owns the bus | use `mode=UR` |
| Nothing boots in Mode B | signed `-t fsbl`, or wrong address | re-sign `-t ssbl`, write to `0x70100000` |
| Stepper does nothing, driver LEDs dark | ground not shared, or wrong pins | Part 5 |
| `No file system is defined for scheme: C` | forward slashes in a headless import path | use backslashes |

---

## Part 10. Current limitations and planned work

MedSight works. It dispenses real pills, counts them, recognises the patient and
keeps a record, on its own power, with no computer attached.

It is a prototype, and five things are not done yet. Each has a plan.

**One medication at a time.** One turntable means one medication, and the
record stores a count rather than a drug name. *Next:* the six to eight stacked
dispensing modules described in Part 5, plus a drug field in the patient record.
The interface already draws four medication slots with three greyed out and
labelled SOON, and the dispense function already takes a count and returns what
was counted, so the firmware change is additive. The mechanical build is the
work.

**It does not know how much is on the turntable.** The first sign of an empty
one today is a dose that comes up short. *Next, and the cheapest useful
improvement in the list:* a carer-entered "filled with N", decremented by
**counted** pills rather than assumed ones, shown as a low-stock warning. It uses
screens that already exist.

**A missed dose cannot leave the room.** There is no radio in this build, which
kept the prototype achievable and means a missed dose waits for the carer's next
round. *Next, and the top of the roadmap:* a **carer alert over Wi-Fi** and a
**patient-worn band** that signals when a dose is due. The firmware hook already
exists, since the scheduler fires exactly once per window, so the work is the
radio, the provisioning and the security design: encrypted to a known endpoint,
carrying the minimum that makes the alert actionable, with a deliberate answer
to where the record comes to rest, and behaving exactly as it does today if the
link is down.

The alerting side is planned as a **separate companion unit first**, proved on
its own before any of it is folded into the dispenser, so that a fault in a
radio can never take the dispensing path down with it. Folding it in afterwards
means a **flexible printed circuit** in place of the loose harness this
prototype uses, which is the step that turns two boxes into one product. All of
it stays under the same open licence as the rest of this work.

**The face check can be shown a photograph.** Recognition compares a face
against an enrolled fingerprint. It does not test whether the face in front of
it is a live one, so a printed photograph or a phone screen held up to the
camera would pass. In a shared room with a carer present that matters less than
it would in an unattended machine, but it is a real gap and it belongs in the
list rather than waiting to be discovered. *Next:* a liveness check on the same
camera and the same accelerator the match already runs on. This sensor gives no
depth, so the approach is the one that suits a single colour camera: a passive
test for the texture and the small involuntary motion that a flat reproduction
does not have, run on frames that are already being captured, before a match is
accepted rather than after.

**The housing does not lock.** It is a printed prototype shell, which matters
because care regulations in most places require medication to be stored locked.
The device does *withhold* - it refuses a dose outside its window and to a face
it does not recognise - but it does not *lock*. *Next:* a lockable enclosure,
tamper detection, and a vibration sensor so the log can say when the unit was
shaken. Logging is the whole response: a dispenser that stops working because it
was jostled is a hazard.

**And one thing worth being clear about.** The device counts pills leaving the
turntable and corroborates a swallowing gesture; it cannot prove somebody
swallowed, and no device of this class can. That is why the button the patient
presses remains the confirming action and the camera's verdict is evidence in
the log rather than the verdict. Face matching is likewise a similarity score
rather than an identity guarantee. Testing so far is four dispense trials, 13 of
13 pills, with no deliberately induced jam and no trial with the people the
device is designed for. That is the honest state of a working prototype, and it
is what the next round of work is for.

---

## Thank you

MedSight was built by five of us.

| | |
|---|---|
| **Dousik Manokaran** (applicant) | The firmware: the µT-Kernel migration, the six-task architecture and its priorities, the four networks on the accelerator, and this handbook |
| **Howard Nikhil** | The physical dispensing hardware: the turntable, the infrared pill counter, and the bench work the counting design rests on |
| **Gaurav V R** and **Dillimaran K** | The three-stage intake pipeline - detection, geometry, temporal decision - and the guarded state machine that refuses to certify an intake it cannot support |
| **Abirami M** | The visual identity: the mascot, and the artwork all twenty-two screens are cut from |
| **Dr. G. Santhanamari** and **Dr. D. Selvakumar** | Supervision, and two roadmap items: the vibration sensor for tamper detection, and the patient-worn alert band |

Our thanks to the **TRON Forum** for the opportunity, and for the STM32N6570-DK
board that made the second round possible. Building on µT-Kernel 3.0 at this
scale was the part we enjoyed most: the task priorities here are derived rather
than argued, the four networks run on the board's own accelerator, and every
number in this handbook came off the device.

We would like to keep going: the radio, the extra dispensing modules, and a trial with the
people this is actually for. Thank you for reading.

---

*µT-Kernel 3.0 is © TRON Forum and Ken Sakamura under T-License 2.1 / 2.2, and
the board was supplied by the TRON Forum. MedSight's own code, documentation
and CAD are Apache-2.0. Third-party components and their licences are
inventoried in `THIRD_PARTY_SOFTWARE.md`.*

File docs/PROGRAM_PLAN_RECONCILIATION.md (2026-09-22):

# The plan against what was built

MedSight, entry 54916. Compared against the Program Plan submitted 31 March 2026
for the first screening round.

The plan described a **camera-only device**: a user holds a medication packet up
to the camera, a CNN classifies it, and the result is checked against a stored
schedule. What was built dispenses, counts, recognises the patient and
corroborates that the dose reached their mouth.

---

## Summary

| Promised | Status |
|---|---|
| Fully offline operation | **Delivered** |
| On-device NPU inference | **Delivered**, four networks rather than one |
| Caregiver notification flag in non-volatile memory | **Exceeded**, a full append-only event log readable on the device |
| Multi-patient support, listed as extensibility | **Delivered** as a core feature |
| RTOS task architecture, four tasks sketched | **Exceeded**, six tasks with priorities derived rate-monotonically |
| Schedule validation | **Delivered** |
| Audio and visual alert feedback | **Delivered**, five buzzer patterns and on-screen alerts |
| Open source commitment | **Kept**, Apache-2.0 |
| **On-device CNN pill classification** | **Not built.** See below |

| Not promised, delivered anyway |
|---|
| Face recognition and patient identity verification |
| Physical dispensing, with a counted pill sensor |
| Action recognition, two further networks |
| Carer mode behind a passcode, with on-device log review |
| Boot from external flash, running on battery |
| The µT-Kernel migration itself |

---

## The one thing that was promised and not built

The plan committed to *"on-device CNN-based pill/packet visual classification
using the board's NPU"*. That does not exist, and no amount of framing makes it
exist.

**What replaced it: the turntable.** One medication per turntable, separated
physically, which is foolproof in a way vision is not. A vision classifier can
misread a pill; a physical separation cannot.

**What the freed capacity went to** is the question the plan never asked: *did
the patient actually take it?* That is what face recognition and action
recognition answer.

The adherence chain the device implements is five measured links where the plan
offered one inferred one:

1. A carer loads one known medication onto the turntable.
2. The mechanism dispenses a counted dose of it.
3. Face recognition establishes who is taking it.
4. The schedule establishes that it is the right time.
5. The camera establishes that it went towards the mouth.

**One residual risk is unmitigated.** A turntable loaded with the wrong drug
produces a correct, confident, entirely wrong record. Nothing the device does
catches that.

**The pill detector is not a classifier.** It finds *a* pill; it does not
identify *which* medication. That is a narrower claim than the plan made, and it
is made narrowly.

---

## Physical dispensing was added, not restored

The plan contained no dispensing hardware at all. An intermediate revision of
this project's own planning expanded to a stacked-module mechanism, then cut it
entirely as not achievable in the time available, then built one module when the
team's hardware work made it possible.

So the device that ships is **scope added beyond the plan**, not a promise
recovered. The plan asked for a camera that identifies a pill; what arrived is a
machine that dispenses one, counts it out, watches it go to a mouth, and writes
down what happened.

The simulated dispense path was kept working throughout, which is why
`MEDSIGHT_PHYSICAL_DISPENSER` set to 0 remains a supported configuration rather
than dead code.

---

## Is the submission in line with the plan?

Three parts, and the first is a concession.

**One promised core function was not built.** On-device pill classification does
not exist.

**Everything else in the plan was delivered, and most of it exceeded.** Offline
operation, NPU inference, schedule validation, the caregiver record,
multi-patient support, the task architecture and the alert feedback are all
present, and four of those are materially more than the plan described.

**The substitution stands on its own terms.** The plan's classifier answered
*which pill is this?*, and the turntable answers that by construction before the
pill is ever dispensed. The harder and more clinically meaningful question, *did
the patient take it?*, was not in the plan at all and is what the delivered
device addresses.

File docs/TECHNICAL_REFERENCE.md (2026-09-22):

# Technical reference

MedSight, entry 54916. How the firmware is built, and every measured number.

| Part | |
|---|---|
| A | The RTOS: tasks, priorities, the kernel primitives used and rejected |
| B | Software structure: modules, the OS abstraction boundary, the state machine |
| C | The AI pipeline: four networks, what each decides |
| D | Memory: the regions, and what the accelerator can reach |
| E | Every measured number, and how it was obtained |

---

# Part A. The RTOS

## A1. Tasks

Six tasks. Priorities were derived rate-monotonically, shortest period first,
with each number justified rather than inherited. Priority 5 is highest.

| Priority | Task | Period | Why it sits there |
|---|---|---|---|
| 5 | Camera / ISP | 1 ms | The only task tied to external hardware timing. It must consume each frame's statistics before the next frame arrives, about every 33 ms at 30 fps. Missing it degrades exposure and white balance visibly |
| 4 | User interface | 10 ms | Touch-to-response budget. A 10 ms poll plus a 4 fps animation gate stays an order of magnitude inside the roughly 100 ms at which input lag becomes noticeable |
| 3 | AI | on demand | **No deadline.** Hundreds of milliseconds of accelerator work per request, a few times per session, in response to a button press the user already expects to take a moment. Deliberately below the interface so it is preemptible, which is what keeps touch alive during inference. Above the logger because a person is waiting on its result and nobody waits on a log line |
| 2 | SD logger | event-driven | Tolerates seconds of latency by construction. The asynchronous queue exists so no caller ever waits on a 10 to 50 ms card write |
| 1 | Heartbeat | 500 ms | No deadline at all. Deliberately lowest, so "the LED stopped blinking" means "something above me is starving the system", which is exactly the signal it should carry |
| 1 | Alert | event-driven | Sleeps until a pattern is requested, then toggles a pin through a few hundred milliseconds of tone. Shares the lowest level deliberately: a buzzer that delays the camera task to finish a beep is a defect, and a beep arriving 5 ms late is not perceptible |

The application uses 1 as lowest; the abstraction layer inverts this onto the
kernel's opposite scale. Only the ordering is load-bearing, and the absolute
numbers leave headroom on both sides of the kernel's maximum.

## A2. The primitives that are used, and why each is the right one

**Inference is dispatched through an event flag.** The interface's wait has
three outcomes to distinguish in one blocking call: face found, no face, or the
AI task never answered. That is what an event flag expresses and what a queue, a
semaphore or a mutex cannot. The behavioural payoff is real: touch and the
physical button stay alive during a capture, where before the whole interface
task blocked inside the accelerator for seconds.

Action recognition later earned the same primitive again, because the AI task
must block on *a capture request or an intake request* in one call.

**Dose scheduling is an alarm handler**, one-shot, re-armed for the window's
closing edge and then for the next dose. A task polling the clock would wake
8,640 times a day to act four times, and would spend the whole power figure
doing it. The handler runs in handler context, so it sets one bit in an event
flag and returns; every line of actual work is done by a task.

**Deferred object creation bridges a real kernel constraint.** Kernel objects
can only be created once the kernel is running, but every creation call in this
codebase happens before the scheduler starts. The abstraction layer defers real
creation to its own entry point, and callers never see it.

## A3. Two primitives evaluated and deliberately not adopted

**A fixed-size memory pool.** This firmware has no fixed-size runtime allocation
site at all, so adopting one would have meant inventing an allocation in order
to have something to pool.

**An event flag for the dose-confirmation state.** All three of its conditions
are produced by the task that would wait on them.

Neither primitive would have done any work here, and a primitive that does no
work is harder to read than one that is absent.

## A4. Three things that deliberately did not get a task

| | Why not |
|---|---|
| **Scheduled dosing** | Its work is an alarm handler plus a few lines of reaction in the interface task, which already runs every 10 ms and already owns every screen the reaction touches |
| **Action recognition** | Runs on the existing AI task, woken by a fourth bit on the same event flag. A second AI task would have turned the framebuffer ownership rule into a race instead of an invariant |
| **The dispenser** | Runs synchronously on the interface task, because the interface has nothing else to do while a dose is delivered and the progress bar it draws is driven by the same callback. The part that must be asynchronous already is: it is an interrupt handler |

**The buzzer did get a task**, and the contrast is the point: its work is a
sequence of timed waits. Driving it from the 10 ms interface task would either
block every screen for the length of a beep or smear the pattern across
iterations, and the shape of the tone is exactly what distinguishes a polite
patient reminder from an insistent carer alert.

## A5. Power

The vendored board package ships its idle hook empty, so the kernel's dispatcher
spun the processor at full clock whenever no task was runnable, which in this
application is most of the time. It now forwards to this project's own
low-power idle, which executes a race-free sleep instruction and accumulates the
cycles spent asleep.

**Measured: about 89.6% of wall-clock time asleep, waking about 980 times a
second.**

Two faults sit behind that number and both generalise.

**Sleep hung the board, and the interrupt mask was why.** The idle path runs
with a priority mask set, and the system timer's priority is the same value. A
wake-up event must be an exception that would preempt the current execution
priority, and the architecture excludes one masking register from that judgement
but not the other, so the timer could not wake the core and a plain sleep
instruction froze the system the instant it first had nothing to run.

**Putting a processor to sleep is a system-wide change, not a power tweak.** The
sleep state stops the clock of every peripheral, bus and memory whose low-power
enable bit is clear. The framebuffer lives in banks that were affected, so every
idle tick cost the display controller either its own clock, the bus clock, or
the memory it was reading. The panel greyed out while every register the
processor could read said the display was healthy, because the processor only
reads when it is awake. The measurement that isolated it removed the sleep
instruction and changed nothing else.

## A6. The modification surface

**Six vendored kernel files differ from upstream, and every file that implements
a system call is byte-identical.** No kernel call appears anywhere outside this
project's own abstraction layer. The full table with the reason for each change
is in `THIRD_PARTY_SOFTWARE.md` section 4.

---

# Part B. Software structure

## B1. The abstraction boundary

Every application call reaches the kernel through one file. The risk it was
introduced against was explicit: the kernel API might differ enough from the
previous RTOS that the mapping breaks something subtle. Isolating that to one
file kept the blast radius to one file, and when the migration happened, it did.

## B2. Frame buffer ownership

There is **one** framebuffer, and three things write to it: the camera's DMA,
the interface's drawing code, and the accelerator, because the generated network
code places its working memory overlapping the same address.

A second framebuffer was tried, so the interface could keep drawing during
inference. A marker written into it came back overwritten, and rather than work
around that by shrinking buffers or relocating the accelerator's memory pools,
the single buffer was kept. Extracting every address literal from the generated
networks then confirmed why: the second buffer sat entirely inside the
accelerator's working region. There is arithmetic behind that
rather than one observation.

**What ships instead:** the display layer is switched off for the capture
window, so the panel shows a flat colour instead of a frame being visibly
scribbled over. It reads as a deliberate pause rather than a fault.

## B3. The dispenser driver

**One atomic store per step.** The half-step table holds fully-formed register
words rather than per-pin booleans, so advancing the motor is a single 32-bit
write. There is no read-modify-write, so an interrupt landing mid-step cannot
leave two coils energised in a combination the table never contains. The coils
are switched off on every exit path including error paths, so a stepper is never
left drawing holding current after a failed dispense.

**The interrupt timestamps, the task decides.** Both signal edges are timestamped
in the interrupt handler. Breaks shorter than the measured chatter floor are
discarded there; surviving durations go into a 16-entry ring drained from task
context. Nothing prints from the handler, nothing allocates, and the counting
decision lives where it can block safely.

**One bound, on the right quantity.** The original design had a stall bound of
1500 ms on how long the sensor may stay asserted, plus an absolute cap on the whole
dispense. The first standalone run produced legitimate single-pill breaks of 852
and 1210 ms: 290 ms of margin on a medication device, where tripping the bound
means refusing a dose that was being delivered correctly. The absolute cap
measured the wrong thing too, punishing a slow dose rather than a stopped one.

Both are gone. One bound remains, 25 seconds since the **last counted pill**,
restarted by every pill. A working mechanism runs as long as it needs; a stopped
one is caught within one window, including the pill-stalled-at-the-sensor case, which
simply stops producing counts.

**A jam is not a system fault.** The error handler is not called anywhere in the
dispenser. A jam is a normal outcome of a mechanical device, and both failure
outcomes have screens, audit entries and recovery paths.

## B4. The audit log

Written once, after the outcome is known:

```
DISPENSE: <patient> <n> requested, <m> counted (<result>)
```

Logging the intent beforehand and the result afterwards would leave a record
reading as two claims about one event, so the line is written only once.

## B5. The interface

22 screens drawn from one visual system: one frame, one title bar treatment, one
button primitive, one two-button layout, four anti-aliased proportional
typefaces, and colour used as identity, so one colour means one medication
everywhere it appears.

**Three design decisions worth recording:**

A stepped date entry was replaced by typed digits. The stepper made an invalid
date impossible to enter and was miserable: setting a year, day and time from
the power-on default is on the order of a hundred taps. A carer setting the
clock already knows the date; the job is to let them type it. Twelve digits and
a confirm is thirteen taps, and validation is one call at the end. The
dose-times screen went the same way, and the device's own log showed why: that
screen was opened and saved six times in one session when it used a 15-minute
stepper.

Stepping survives on exactly one screen, dose size from 1 to 10, where every
value is at most five taps away and the control shows the whole range
implicitly. That is what stepping is good at.

**The delete confirmation times out to KEEP.** Every other timeout in this
interface goes forward; this one goes back, because that is the only correct
default for something that cannot be undone.

---

# Part C. The AI pipeline

## C1. The four networks

| Stage | Model | Decides |
|---|---|---|
| Face detection | CenterFace, INT8 | Who is at the device. Also supplies both mouth corners |
| Face embedding | MobileFaceNet, INT8 | Whether they are an enrolled patient |
| Hand | MediaPipe hand landmarks, 224x224 INT8, 21 keypoints | Whether a hand reached the mouth |
| Pill | Single-class detector, 160x160 INT8, head removed | Corroboration only. Never creates a detection |

## C2. Face recognition

CenterFace locates a face; MobileFaceNet turns the crop into a 128-dimension
fingerprint; the fingerprint is matched by cosine similarity against the
enrolled gallery at a threshold of 0.65. The gallery is a fixed-size array
sized by `MAX_PATIENTS`, 10 in this build: the bound is RAM, not the matching,
which is a linear scan over 128-byte embeddings and costs nothing worth
measuring at this scale.

Everything around those two networks is this project's own code: the frame
snapshot, the detection box decode, normalisation, 8-bit quantisation of the
fingerprint, the cosine matching, and persistence to the card.

**The threshold was deliberately not moved blind**, because loosening it trades
a recoverable false rejection for a false acceptance.
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

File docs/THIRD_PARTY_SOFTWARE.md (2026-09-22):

# Third-party software

MedSight, entry 54916.

---

## 1. Summary

| Layer | Component | Rights holder | Licence |
|---|---|---|---|
| RTOS | µT-Kernel 3.0 BSP2 | TRON Forum / Ken Sakamura | T-License 2.1 / 2.2 |
| CPU support | CMSIS Core (Cortex-M55) | Arm Limited | Apache-2.0 |
| Device support | STM32N6xx CMSIS Device | Arm Limited, STMicroelectronics | Apache-2.0 |
| Peripheral drivers | STM32N6xx HAL / LL | STMicroelectronics | BSD-3-Clause |
| Board support | STM32N6570-DK BSP and components | STMicroelectronics | BSD-3-Clause |
| Camera ISP | STM32 ISP Library, eVision AE/AWB | LACROIX-Impulse, STMicroelectronics | ST SLA0044 |
| NPU runtime | ST Edge AI runtime 1.1.3-262 | STMicroelectronics | ST SLA0044 |
| AI model | CenterFace face detector | STMicroelectronics | ST SLA0044 |
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

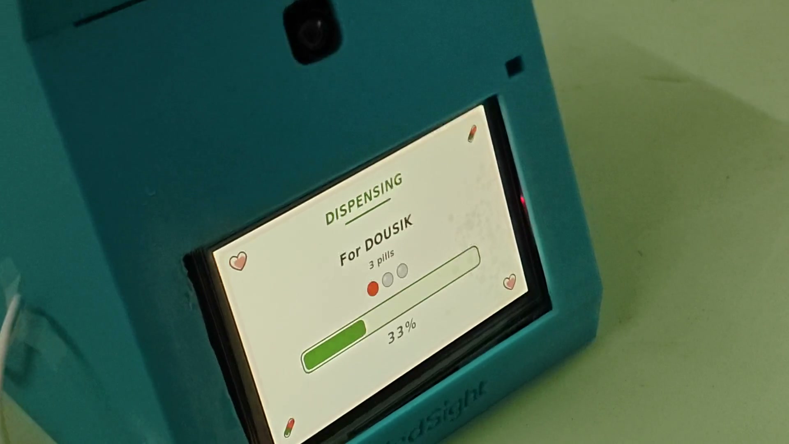
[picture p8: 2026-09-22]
media/demo_poster.jpg

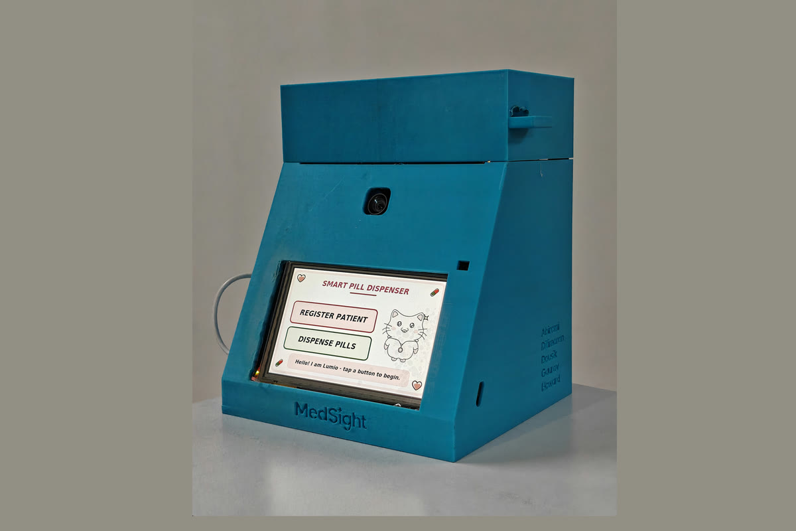
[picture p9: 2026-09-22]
media/hero_poster.jpg

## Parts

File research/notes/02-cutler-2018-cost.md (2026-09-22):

# [2] Cutler et al. 2018 - economic impact of non-adherence

**Claim it supports:** non-adherence carries a large but poorly-bounded cost.

**The number:** $949-$44,190 per person per year, disease-specific, 2015 US$,
across 79 studies and 14 disease groups. All-cause figures ran $5,271-$52,341.

**The caveat, which is the whole reason this source was chosen over a bigger
headline:** the review's own conclusion is that the evidence is limited and of
varying quality, that methods differ enough to make studies incomparable, and
that an accurate estimate of the true magnitude is *impossible*. Only 10 of 79
studies rated high quality.

**Therefore:** quote the range and the uncertainty. Never a single national
total. A source that reports that its own field cannot yet produce a reliable
number is being used honestly only if that finding is passed on with it.

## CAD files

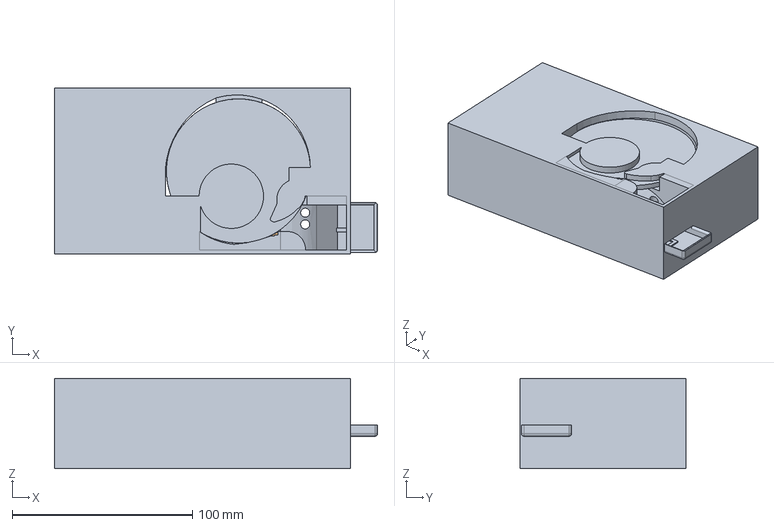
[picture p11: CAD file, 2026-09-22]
hardware/cad/pill_dispenser.step
179.2 x 92.0 x 50.0 mm

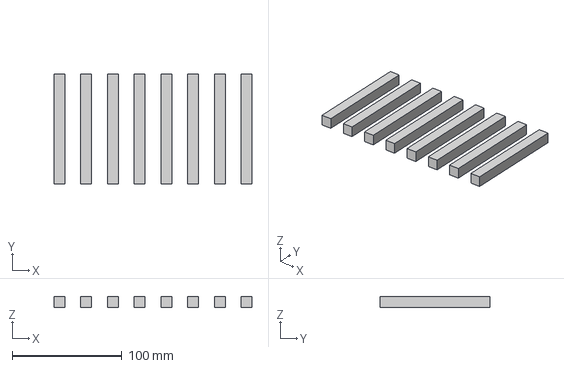
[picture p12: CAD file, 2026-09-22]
hardware/cad/structural_pillars.step
180.0 x 100.0 x 10.0 mm

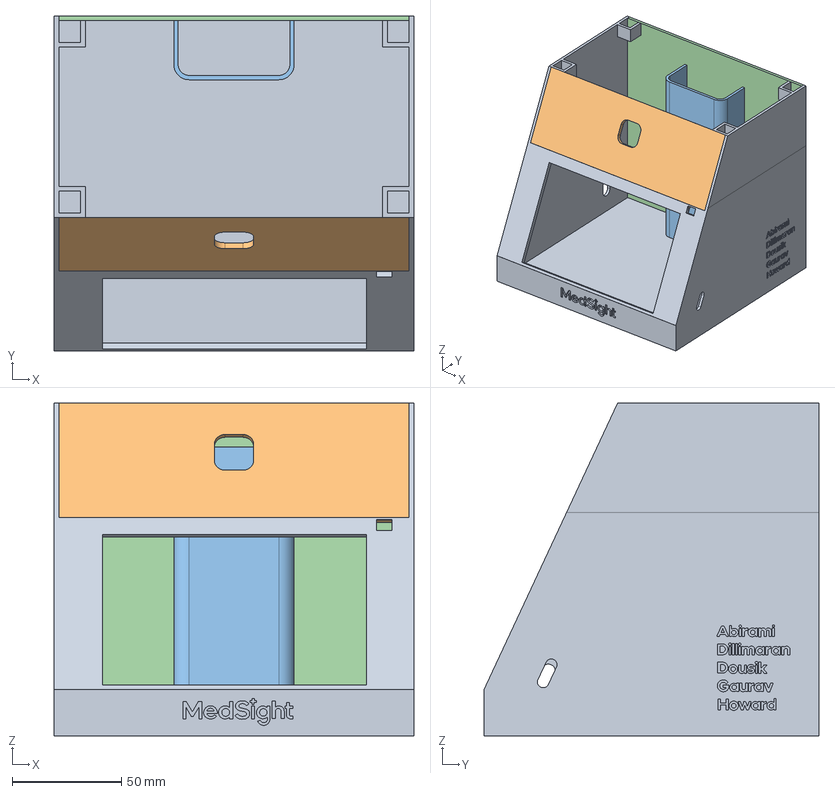
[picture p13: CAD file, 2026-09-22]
hardware/cad/board_enclosure.step
164.2 x 153.0 x 152.0 mm

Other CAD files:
hardware/cad/board_enclosure.stl
hardware/cad/pill_dispenser.stl
hardware/cad/structural_pillars.stl

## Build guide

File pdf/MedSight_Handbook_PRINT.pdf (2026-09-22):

T R O N P R O G R A M M I N G C O N T E S T 2 0 2 6 · R T O S A P P L I C A T I O N

# MedSight

## A medication dispenser that recognises the patient by face and counts every pill physically leaving the

turntable.

## Most dispensers release pills and assume the rest. This

one measures every step it records.

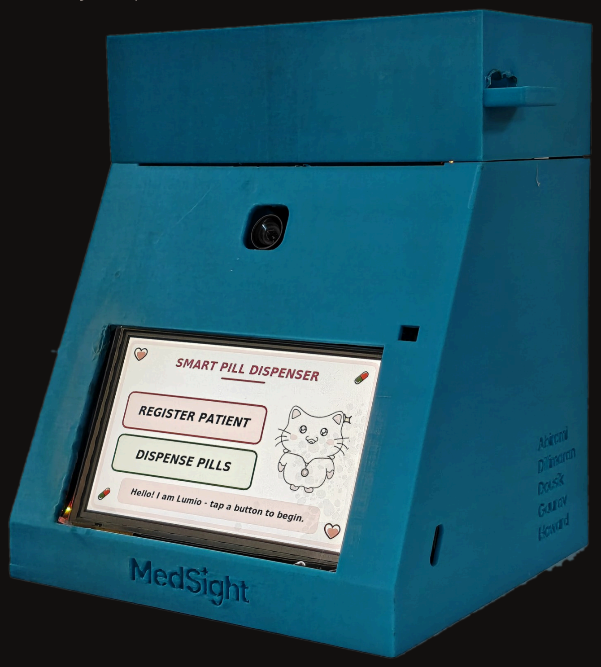
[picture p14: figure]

Dousik Manokaran
Entry 54916 · µT-Kernel 3.0 on STM32N6570-DK m-dousik.github.io/MedSight

Scan for the site, the source and this handbook

W H A T I T I S

# A carer enrols someone once. From then on the device recognises them by face, reminds them when a dose is due, and counts every pill physically

leaving the turntable.

Between a fifth and a half of older patients do not take their long-term medication as prescribed. In care homes, 69.5% of residents in one 55-home study had at least one medication error, and the causes named were workload, interruptions and paper records rather than carelessness.

Most pill organisers are passive. A labelled box does not know who opened it, or whether anything was taken. MedSight puts identity, timing and a physical count of what came out onto the device itself, with four neural networks running on the board and nothing sent anywhere.

One device, many patients, each known by face. Four dose times each. Runs on its own battery, with no mains supply and no computer.

Every figure in this handbook was measured on the real board. Nothing here is an estimate.

# What is in this handbook

What the device is, how it works, how to run it, how to build and flash it, and the planned work.

### 01 System overview

The problem, what the device does about it, and how it differs from existing dispensers.

### 02 The dose sequence

Five stages, end to end, with the count taken from a sensor readout.

### 03 The neural networks

Four networks on the board's accelerator, and the one trained for this project.

### 04 RTOS architecture

Six tasks, the kernel primitives in use, and the measurements.

### 05 Hardware architecture

Eleven interconnects drawn as components, the printed parts, the full specification.

### 06 Quick start

Battery in to first dispense, in ninety seconds.

### 07 Operation

Every flow: doses, enrolment, the clock, schedules, refilling, history, audio patterns.

### 08 Building and flashing the firmware

ST-LINK, the build, the five weight images, signing for standalone boot.

### 09 Troubleshooting

What the screen reports, what it means, and what to do.

### 10 Current limitations and planned work

Where the prototype stands, and the approach for each gap.

P A R T 1

# System overview

The problem
Between a fifth and a half of older patients do not take their long-term medication as prescribed. The range is 21-55%, from a 2026 systematic review of older adults facing treatment burden (Amato et al.), and a second 2026 review across 128 studies searched to the end of 2024 finds the problem no less stubborn (Scotti et al.). On dispensing data rather than self-report, an analysis of 42,601 records for patients over 65 lands in the same place (Cardona et al., 2025). The familiar line that adherence averages 50% comes from the WHO's 2003 review; that report established the baseline and is cited here for that, not as a current measurement.

In residential care it fails differently, and worse. A study of 256 residents across 55 care homes found 69.5% had at least one medication error, at a mean of 1.9 errors each, with residents taking a mean of 8 medicines. The causes named were not carelessness: high staff workload, lack of medicines training, drug round interruptions, paper records, and administration systems that are hard to fill and hard to check.

This is getting larger everywhere. By 2030 one person in six worldwide will be 60 or over, and that population doubles to 2.1 billion by 2050 (World Health Organization, October 2025). Care work is the constraint on top of it: the same body projects a shortfall of about 11 million health workers by 2030, concentrated in low- and lower-middle-income countries.

Most pill organisers are passive. A labelled box does not know who opened it, or whether anything was taken.

What the device does
A carer enrols a patient once: their face, their name, how many pills they take at a time, and up to four times of day. That takes about two minutes and it happens behind a passcode.

From then on the device runs on its own. It reminds the patient when a dose is due. It checks who is standing in front of it, by face, using its own neural processor. It turns a motorised turntable and counts each pill as it physically passes an infrared sensor, so the number on screen is a measurement rather than an assumption. It runs action recognition over the confirmation window. And it writes every one of those events to a memory card that a carer can read back on the device itself.

One device, many patients. Each one is recognised by face and carries their own schedule, up to four dose times a day. One medication per turntable.

How it differs from existing dispensers
It counts, rather than assumes. Any dispenser can turn a motor for a fixed time and hope the right number of pills came out. This one has a sensor in the chute, and the progress bar on screen steps once per pill it actually detects. If three pills come out when four were asked for, the record says three.

It knows who it is dispensing to. Face recognition runs entirely on the board, on a dedicated neural processor, in 209 ms. Nothing is uploaded and no photograph is stored: what is kept is a mathematical fingerprint of the face, not the picture that produced it.

It runs on its own. Signed firmware in the board's external flash, its own battery in the back of the housing, no computer anywhere. It is a device, not a demo.

It does not need anyone's servers. A dispenser with a companion app and an account necessarily moves the adherence record off the device and onto somebody else's machine. This build has no radio at all, so the record stays on the card in the device.

P A R T 2

# The dose sequence

Five steps. The fourth is the one that matters.

### 1 The window

opens

A µT-Kernel alarm handler fires exactly once. The home screen names the patient and the time; three short beeps.

2 Identification | CenterFace detects the face, MobileFaceNet encodes it as a 128-dimension embedding, and it is matched against the enrolled gallery by cosine similarity. 209 ms, every time.
3 Dispense | The turntable turns. Each pill passes the infrared sensor on its way down the chute. Measured pulse: 17- 46 ms, because pills slide rather than fall.
4 Counted, not timed | The progress bar steps once per counted pill. Pill 3 of 6 is a half-full bar reading 50% because three pills were actually counted.
5 Confirmation | Action recognition observes the window. The patient's press of the large green button remains the confirming action. One record goes to the card.

Why step 4 is the one that matters. With the mechanism attached the bar advances on each sensor pulse, so it reports what the hardware actually did. A timed animation exists only in the simulation build, where MEDSIGHT_PHYSICAL_DISPENSER is 0 and there is no sensor to read. That is also why the audit line records the count that actually came out:

DISPENSE: <patient> <n> requested, <m> counted (OK)

written once, after the outcome is known, so the log never contains two claims about one event.

If a dose goes wrong, neither outcome is treated as a system fault, because a mechanical device jamming is normal:

JAM - 25 seconds with nothing counted at all. Nothing was released.
SHORT - some pills, then 25 seconds of silence. The turntable needs refilling.

The 25 seconds measures time since the last counted pill, so a working mechanism can take as long as it needs and a stopped one is caught in one window.

P A R T 3

# The neural networks

Four neural networks run on the board's Neural-ART accelerator. Nothing is sent anywhere.

NETWORK | WHAT IT DECIDES | ORIGIN
CenterFace | Detects a face and emits five landmarks
with it, both mouth corners among them

STMicroelectronics

MobileFaceNet Encodes the face crop as a 128-dimension embedding for cosine matching

STMicroelectronics

MediaPipe hand
landmarks

21 keypoints, giving the fingertip position during the confirmation window

Google, via ST's model zoo. We selected it, quantised it, compiled it to the NPU and integrated it. We did not train it

Pill detector | Single-class detection in a mouth-centred region. Corroboration only

Trained by this team

The pill detector was trained here on a public pill dataset, exported, and adapted to the accelerator: the convolutional body runs as 8-bit integer on the NPU and the YOLO decode runs on the Cortex-M55. It corroborates and does not decide, because at the deployment distance a pill is about an 8-pixel object and per-frame detection is around 7%. On the validation set the 8-bit model matches the floating-point model it was trained from.

Everything around the face networks is our code too: the frame snapshot, the box decode, the normalisation, the 8-bit quantisation of the fingerprint, the cosine matching against the gallery, and writing it to the card.

One measurement worth keeping. The hand model scores 0.0078 on a face, never goes above 0.035 across 400 random images, does not fire on an ear waved deliberately in front of it, and scores about 0.50 on a hand at the mouth. Four rounds of simpler skin-colour heuristics could not separate a moving ear from a hand; a model that knows what a hand is settled it in one step.

P A R T 4

# RTOS architecture

This is entered in the RTOS Application category, judged on real-time performance, power saving and memory footprint. The answer is not "we used an RTOS".

89.6% | of wall-clock time asleep in WFI , waking about 980 times a second
85.6% / 63.0% | of the code and data regions used, leaving 147 KB and 378 KB free

Kernel primitives in use

PRIMITIVE | WHAT IT DOES HERE
tk_cre_tsk | Six tasks, priorities derived rate-monotonically: shortest period gets the highest priority, each number justified in writing. The AI task sits below the interface deliberately, which is what keeps touch and the physical button alive while the accelerator works
tk_cre_flg , tk_wai_flg | Inference is dispatched through an event flag. The interface's wait has three outcomes to tell apart in one blocking call: face found, no face, or the AI task never answered. A queue, a semaphore or a mutex cannot say that. The payoff is behavioural: the interface used to freeze inside the neural processor for seconds
tk_cre_alm , tk_sta_alm | Dose scheduling is an alarm handler, not a task polling the clock. Polling would wake 8,640 times a day in order to act four times, and would spend the power figure above doing it. The handler sets one bit and returns; every line of real work happens in a task
tk_cre_mbf , tk_cre_mtx | The logger's queue, so no caller ever waits on an SD write, and the firmware's one mutex: the clock, which has two readers
low_pow() | The vendored board support package ships its idle hook empty. Ours executes WFI and accounts for the cycles, which is where the 89.6% comes from

One file talks to the kernel. Every call above lives in ms_osal.c , behind an abstraction the rest of the firmware was written against, so the kernel's use is deliberate and in one place rather than scattered. The vendored kernel itself is unmodified except for six files out of about 230, none of which implements a system call.

Two idioms were evaluated and deliberately not adopted, with the reasoning written down: a fixed-size memory pool, because this firmware has no fixed-size runtime allocation site at all and adopting one would have meant inventing an allocation in order to have something to pool; and an event flag for the confirm state, because all three of its conditions are produced by the task that would wait on them. Neither would have done any work.

# Hardware architecture

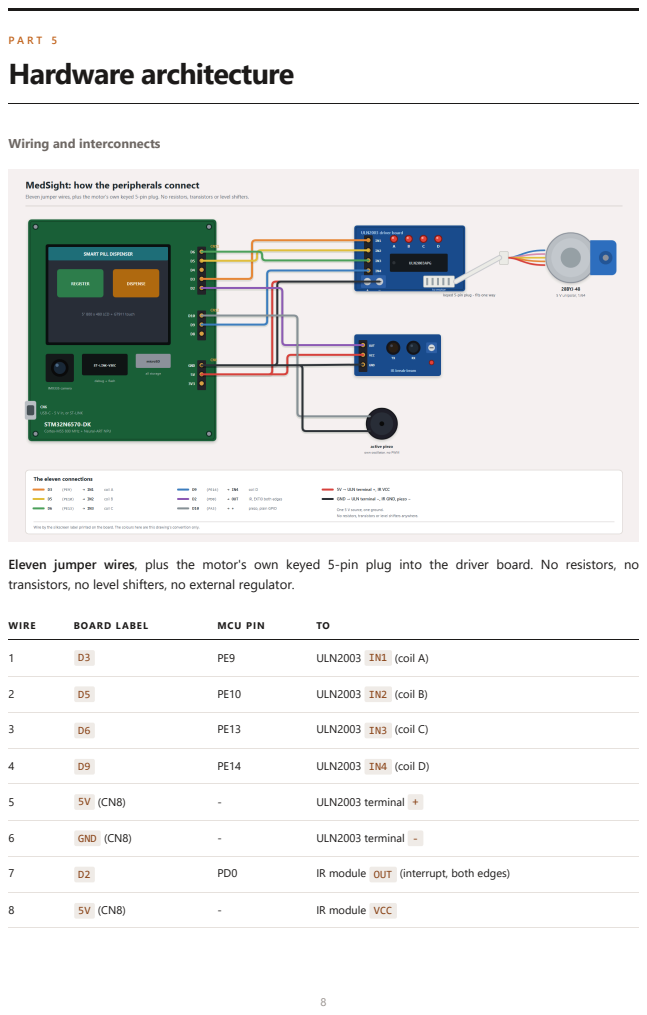
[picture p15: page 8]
WIRE; BOARD LABEL; MCU PIN; ULN2003 IN1 (coil A); ULN2003 IN2 (coil B); ULN2003 IN3 (coil C); ULN2003 IN4 (coil D); ULN2003 terminal +; GND (CN8); ULN2003 terminal -; IR module OUT (interrupt, both edges); IR module VCC

Wiring and interconnects

Eleven jumper wires, plus the motor's own keyed 5-pin plug into the driver board. No resistors, no
transistors, no level shifters, no external regulator.

WIRE | BOARD LABEL | MCU PIN | TO
9 | GND (CN8) | - | IR module GND
10 | D10 | PA3 | piezo +
11 | GND (CN8) | - | piezo -

Wire by the silkscreen label printed on the board, not by the colour in the drawing. The colours above are that drawing's own convention.

D14 and D15 are the camera's I2C and must stay clear.

Power
One 5 V source, one ground.

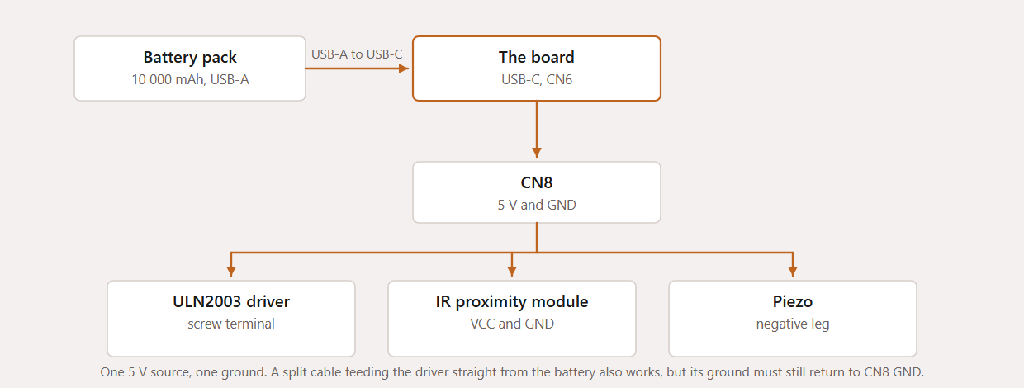
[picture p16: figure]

Running the driver from the board's own CN8 5V was tested under motor load and is the recommended arrangement, because it makes a shared ground structural rather than something you have to remember. A split USB cable feeding the driver straight from the battery pack works too, but its ground must still return to CN8 GND - a driver whose ground floats will not switch, and it looks exactly like a dead driver.

The printed parts


Rendered from the STL files that go to the printer. The callout numbers are:

### 01 Board

enclosure

1 housing shell, 2 port and connector grid, 3 battery compartment, 4 MedSight brand plate

### 02 Pill

dispenser

1 enclosure box, 2 rotating carousel, 3 central drive motor hub, 4 dispensing chute, 5 output collection drawer, 6 side sensor brackets, 7 internal divider wall

### 03 Structural

pillars

1 structural pillar, eight off

PART | SIZE
Board enclosure | 164 x 153 x 152 mm - sloped front face, rear battery compartment
Pill dispenser | 179 x 92 x 50 mm - carousel, motor hub, chute, collection drawer, sensor brackets
Structural pillars, 8 off | 180 x 100 x 10 mm

The chute geometry is what makes the counter work. Pills slide rather than free-fall, which is why detection pulses measure 17-46 ms instead of the few milliseconds a drop would give. A driver sized for a free-fall would have thrown away every real pill.

One sensor, and a threshold set from measurement. The module is a reflective infrared proximity sensor: a pill passing in front of it returns enough light to pull the output low, and the output is digital, so the in-or-out decision is made in the sensor rather than in software. What that costs is honest to state: how strongly a pill returns light depends on its colour and finish, which is why the discrimination floor was set from measured pulse durations rather than assumed.

Specifications

Processor Arm Cortex-M55 at 800 MHz, STM32N657X0H3Q

AI accelerator ST Neural-ART at 1 GHz, about 600 GOPS

Networks on it | 4
Memory | ~4.2 MB on-chip SRAM · 1 Gbit external NOR for weights · 256 Mbit PSRAM

Firmware size 85.6% of the code region, 63.0% of the data region

RTOS | µT-Kernel 3.0, six tasks
CPU idle | ~89.6% in WFI
Display | 5 inch, 800 x 480, capacitive touch
Camera | Sony IMX335
Storage | microSD. The only storage in the device
Clock | internal RTC, kept across resets in the backup domain
Actuator | 28BYJ-48 stepper, half-step, 2 ms per step
Pill sensor | infrared proximity, both edges, 8 ms discrimination floor
Audio | active piezo, five patterns
Power | 5 V USB-C. Runs on its own battery, with no mains supply and no computer
Capacity | multiple patients, 4 dose times each, 1-10 pills per dose, 1 turntable. The gallery size is a build constant, MAX_PATIENTS , set to 10 in this build

Measured performance

Face recognition, end to

end | 209 ms, identical to the millisecond across four captures

Hand-landmark inference 285-302 ms

Pill detector, quantisation 8-bit matches floating point on the validation set. At the deployment distance, per-frame detection is about 7%

Dispense accuracy | 4 trials: 5/5, 3/3, 3/3, 2/2. All 13 pills counted. A small sample, not a reliability figure: the mechanism has miscounted and jammed outside these trials
Longest legitimate detection pulse | 1210 ms

Battery operation | one complete dispense on battery, no laptop

The 209 ms is the same on every capture: four faces, four detector confidences, one timing. The accelerator runs a fixed schedule for a fixed input size, so the cost does not depend on the picture.

P A R T 6

# Quick start

No computer. About ninety seconds.

If the dispensing hardware is damaged or missing, skip to 8.9: the whole application runs without it, with the dispense shown on screen.

1. Check the two settings on the board. Both ship correct and neither needs a tool: - SW1 (BOOT1) must be LOW. - The power-source jumper on the underside of the board must be on USB-C, not STLK and not VIN . This is the one that catches people: on STLK the board takes its power from the debugger, so the battery does nothing and the device looks dead.
2. Check the battery cable is connected. The cable lives inside the housing and is normally left plugged in: USB-C into CN6 on the board, the other end into the battery in the rear compartment. If it has come loose, connect it.
3. Press the power button on the back. It is the battery's own button, brought out through the back panel, and it glows while the battery is supplying power. One press turns the device on. Two presses in quick succession turn it off.


The back of the device. The button is the only control on this face.

4. Wait about ten seconds. The home screen appears: a teal bar reading SMART PILL DISPENSER, two large buttons, and an animated cat.
5. Tap the amber DISPENSE PILLS, then I AM READY.
6. Look at the camera. A live preview, then the screen goes flat pink for about three quarters of a second. That pause is the neural processor running and it is deliberate - its working memory overlaps the display buffer, so the screen is switched off rather than left showing raw tensor data. It is a pause, not a fault.
7. The device greets the patient by name and shows the exact image it ran on, with the detector's box and five landmarks drawn on it. Tap NEXT.
8. Watch the dispense. The turntable turns, each pill passes the sensor, and the bar steps once per counted pill. Two short beeps on success.

The unit as shipped has no memory card fitted. The card is supplied in the packet with the pills. Its slot is on the board, inside the housing, so fitting it means opening the enclosure. Until it is fitted the home screen says so in those words: No SD card - doses are not being recorded. The device still works normally. Everything described in this handbook runs without it. What does not survive a power cycle is the enrolled gallery, the dose history, and any change to the carer passcode; fit the card and all three persist.

Two LEDs tell you the RTOS is alive. The green one toggles once per iteration of the 1 ms camera task, so at about 500 Hz your eye reads it as a steady dim glow. The red one toggles every 500 ms in the idle task, a 1 Hz blink. Both ends of the priority range, visibly running, on battery.

P A R T 7

# Operation


Everything in this part happens on this screen. The camera is the small lens above it; the dose arrives in the drawer below.

### 7.1 Carer mode

The passcode is 1234 . It is a build-time default, the device says on every boot that it is still on the default, and it can be changed.

To get in: tap the title bar, the coloured strip across the top of the home screen, five times within three seconds, then type the passcode.

The title bar is the target because it is the one thing on that screen that is unmistakably not a button, so nobody taps it five times by accident. Any tap elsewhere resets the count.

### 7.2 A ten-minute evaluation

# STEP | HOW | EXPECTED

1 Power on | battery pack to CN6 | home screen
2 Enter carer mode | title bar x5 in 3 s, then 1234 | CARER MODE menu
3 Set the clock | SET CLOCK , twelve digits DDMMYYYYHHMM , OK | "Clock set."
4 Leave carer mode | EXIT | home screen, schedule armed
5 Register a patient | REGISTER PATIENT , 1234 , I AM READY , type a name, DONE , face the camera, NEXT , set pills per dose, NEXT , CONFIRM | "Registered!"
6 Set a schedule | carer mode, PATIENTS , the name, DOSE TIMES , tap a slot, four digits, OK , SAVE

"Dose times saved."

7 Dispense | home, DISPENSE PILLS , I AM READY , face the camera, NEXT | greeted by name; bar steps per pill; two beeps
8 Confirm | the large green I TOOK IT! | "THANK YOU!"
9 Read the log back on the device | carer mode, REVIEW LOG | the last few lines. Missed doses are the one line that is not grey
Step 5 is worth watching for one detail. The passcode is asked before the camera is ever used. Asking afterwards would mean a face and a name had already been taken from somebody who was never authorised to give them.

### 7.3 Registering somebody

REGISTER PATIENT , passcode, I AM READY , type the name, DONE , the person looks at the camera, NEXT , set the pill count, NEXT , CONFIRM .

The name is asked before the photograph on purpose: being photographed by a machine that has not yet asked who you are is the wrong way round.

Enrol in the light the device will be used in. This is the single most useful thing you can do. One test round measured match scores of 57 to 88 for the same person under varying illumination, rejecting them about one time in three. That is a property of one-shot face recognition, not a fault, and the retry screen rescued every case - but a demo filmed in different light from the enrolment will show that retry screen.

### 7.4 The clock

Set it first on a new device. The device has no network, so it cannot set its own clock, and a wrong clock gives doses at the wrong time with an audit trail that says it was right.

Carer mode, SET CLOCK , twelve digits: day, month, year, hour, minute. For 7 March 2027 at 08:30, type 070320270830 . An impossible entry names the field that is wrong rather than just saying invalid.

### 7.5 Dose times and dose size

Dose times: carer mode, PATIENTS , the name, DOSE TIMES . Four slots. Tap one, type four digits, OK , SAVE .

Dose size: carer mode, PATIENTS , the name, DOSE SIZE , - and + , one to ten, SAVE . This is how many pills at once, not how many are in the machine.

### 7.6 Refilling

The turntable is open from above. Lay pills loose on it. They do not need arranging: the guides singulate them as the disc turns.


The turntable, from above. Pills lie in a single layer and the guide feeds them to the chute one at a time.

The device does not track how many pills are on the turntable, and that is a decision rather than an oversight: it has no way to know when a carer tops it up, so rather than keep a number that would quietly go wrong, it keeps none. So check the turntable on a routine, not when the device asks.

If it jams or loses power, open the housing and take the dose out by hand. The case does not lock and nothing holds the pills in. A machine must never stand between somebody and their medication.

### 7.7 The dose history

Carer mode, REVIEW LOG .

LINE | MEANING
DISPENSE | pills came out, and how many were counted
CONFIRMED | the patient pressed I TOOK IT
SKIPPED | the patient pressed Skip
MISSED | a window opened and closed with nothing dispensed

Missed doses are shown in colour; everything else is grey.

### 7.8 Audio patterns

SOUND | MEANING | FOR
One very short blip | you tapped something | whoever is tapping
Two short beeps | the dose came out correctly | the patient
Four quick short beeps | jam, or the turntable is empty | whoever is there
Three pairs of short beeps | pills are due now | the patient
Four long beeps, twice | a dose was missed | the carer

Only the missed-dose alert uses long tones, and that is deliberate. The reminder is polite because it fires on schedule when nothing is wrong. The missed-dose alert is insistent because by then something is, and it is aimed at a carer, not the patient: somebody who has already not responded to a reminder does not need to be beeped at harder. The long beeps exist to bring a carer to the device.

### 7.9 Removing somebody

Carer mode, PATIENTS , the name, DELETE , DELETE again.

This removes their name and their face data together. A partial delete would defeat the point: a record with a cleared name and a live fingerprint still matches a face, it just matches it to nobody.

The confirmation screen times out to KEEP. Every other timeout in this interface goes forward; this one goes back, because that is the only correct default for something you cannot undo.

### 7.10 The camera during the confirm screen

The camera runs for up to 30 seconds on the TAKE YOUR PILL NOW screen, looking for a hand going to the mouth.

No picture is ever saved, to the card or anywhere else. What survives is a few words in the history.

Nothing on screen announces this, deliberately: a warning on the one screen where somebody is being asked to do something simple risks distracting them from doing it. A person being watched by a camera should still be told, so tell the patient and their family.

P A R T 8

# Building and flashing the firmware

Every command here was actually run.

What you are building. This firmware starts from ST's STM32N6 example application and replaces its core. µT-Kernel 3.0 is the RTOS, reached through an abstraction layer written for this project; six vendored kernel files differ from upstream and every file implementing a system call is byte-identical. The OS abstraction layer, the 22-screen user interface and its design system, the state machine, carer mode, the scheduler and time source, the SD logger and the block-device layer beneath FatFs, the dispenser driver and the alert path are original MedSight code. Four neural networks were selected, quantised, compiled to the accelerator and integrated. Every third-party component, its rights holder and its licence are inventoried in
THIRD_PARTY_SOFTWARE.md .

### 8.1 What you need

STM32CubeIDE 2.1.1 or newer. There is no .ioc file: every peripheral is configured in code rather than generated, so there is nothing to regenerate.

STM32_Programmer_CLI | and STM32_SigningTool_CLI | ship inside CubeIDE, with the external loader
MX66UW1G45G_STM32N6570-DK.stldr beside them. Set these once per PowerShell session:

$BIN = "C:\ST\STM32CubeIDE_2.1.1\STM32CubeIDE\plugins\com.st.stm32cube.ide.mcu.externaltools.cubeprogr ammer.win32_2.2.500.202603051304\tools\bin"
$CLI | = "$BIN\STM32_Programmer_CLI.exe"
$SIGN | = "$BIN\STM32_SigningTool_CLI.exe"
$LOADER = "$BIN\ExternalLoader\MX66UW1G45G_STM32N6570-DK.stldr"

Your plugin folder's version suffix will differ. dir "$BIN\.." to find it.

### 8.2 The one rule for external-loader operations

After any external-loader operation, unplug the USB cable.

Not a reset. Not the IDE's stop button. The cable, out, for a few seconds.

Back-to-back operations through the external loader leave the flash chip's bus state confused. The symptom is a boot that hangs where the external flash is first touched: the log stops right after ai_vision_init: DEBUG build (-O0). and the screen holds a stale frame. The flash contents are fine; only the peripheral's bus state needs clearing.

This applies to reads as well as writes. A verification read leaves the bus in the same state a write does, and a read is exactly when it is most tempting to leave the board running.

### 8.3 Boot switches

MODE | SW1 (BOOT1) | SW2 (BOOT0)
A, development | HIGH | LOW | waits for the debugger, gives you the log
B, standalone | LOW | LOW | runs from external flash, no computer

Mode A is the factory position and is enough to evaluate every software feature.

### 8.4 Build

Import firmware/STM32CubeIDE/FSBL and build Debug. Expect 0 errors, 0 warnings.

Headless:

& "C:\ST\STM32CubeIDE_2.1.1\STM32CubeIDE\stm32cubeidec.exe" --launcher.suppressErrors -nosplash ` -application org.eclipse.cdt.managedbuilder.core.headlessbuild `
-data <a scratch workspace dir> `
-import "firmware\STM32CubeIDE\FSBL" `
-cleanBuild "MedSight_FSBL/Debug"

On Windows the -import path must use backslashes; a forward-slash path with a drive letter is parsed as a URI scheme and fails.

### 8.5 Flash the neural network weights

The firmware does not contain its neural network weights. The linker marks those external flash regions as not-to-be-loaded, deliberately, so building and flashing the application never writes them.

A fresh clone therefore compiles a perfectly good binary, flashes it, and produces a device whose face recognition and pill detection both output nonsense, with nothing in any log to say why.

Five images, once per board:

& $CLI -c port=SWD mode=UR -el $LOADER -w "weights\fd_data.xSPI2.bin" | 0x70380000
& $CLI -c port=SWD mode=UR -el $LOADER -w "weights\ec_blobs.xSPI2.bin" | 0x71000000
& $CLI -c port=SWD mode=UR -el $LOADER -w "weights\faceid_data.xSPI2.bin" | 0x72000000
& $CLI -c port=SWD mode=UR -el $LOADER -w "weights\hand_atonbuf.xSPI2.bin" 0x73000000 & $CLI -c port=SWD mode=UR -el $LOADER -w "weights\pill_atonbuf.xSPI2.bin" 0x73400000

Then unplug the cable (see 8.2).

REGION | ADDRESS | WHAT
fd_data | 0x70380000 | face detector weights

REGION | ADDRESS | WHAT
ec_blobs | 0x71000000 | accelerator microcode
faceid_data | 0x72000000 | face embedder weights
hand_atonbuf | 0x73000000 | hand landmark model
pill_atonbuf | 0x73400000 | the pill detector we trained

SHA-256 prefixes for all five are in weights/README.md , so a mis-copied file is caught before it becomes a debugging session.

Use mode=UR , not mode=HOTPLUG . HOTPLUG needs a live, responsive core, and with MedSight running the erase fails outright, because the application has the external flash memory-mapped while the loader wants the same bus in indirect mode.

### 8.6 Flash the application

Move the power-source jumper on the underside of the board to STLK first, so the board is powered by the debugger while it is being programmed. Move it back to USB-C before running on the battery. It is the same jumper the quick start mentions, and it is the usual reason a flash or a standalone boot fails for no visible cause.

In the IDE, press Run. The launch configuration is committed and needs no editing. From a terminal instead:

& $CLI -c port=SWD -w "firmware\STM32CubeIDE\FSBL\Debug\MedSight_FSBL.elf" -rst

Use -rst , a software reset. An explicit go-to-address was tried and did not reliably produce a running application on this board. This command never touches external flash, so it is the fast every-edit loop.

### 8.7 Watch the log

ST-LINK virtual COM port, 115200 8N1. A correct boot says, in order:

ai_vision_init: face detector + embedder ready.
ARENA SELFTEST PASS: 225280 bytes writable and readable
intake: hand landmark model ready (MediaPipe 224x224 INT8, 21 keypoints, ...) intake: pill detector ready (YOLOv8n 160x160 INT8, head cut, decode on CPU). dispenser: ...
buzzer: active piezo on PA3 (Arduino D10), keyboard click off task_camera_isp: started.

If detection runs but the numbers are meaningless, suspect a weight region before you suspect the code. A missing or wrong weight image does not announce itself as an error: the network initialises cleanly and returns nonsense.

### 8.8 Standalone boot

Why it takes two stages. The STM32N6 has no internal flash. Its boot ROM copies a first-stage loader from external flash into RAM, and that copy is capped at 512 KB. MedSight is about 880 KB, so it can never be the first stage.

STAGE | WHAT | ADDRESS
1 | ST's prebuilt loader ( ai_fsbl.hex ) | 0x70000000
2 | MedSight, signed as second stage | 0x70100000
- | Neural network weights, untouched | 0x70380000 +

Get ST's loader. It is not in this repository because it is ST's binary, not ours. Download X-CUBE-N6-AI-POWER-MEASUREMENT v1.4.0 or newer and take FSBL/ai_fsbl.hex . The copy verified against:

sha256 8fa77dcdcb9aeed6e167c1ce5ffe9e16071fdeced8d13e22edd31a37abed1993
size 176,541 bytes

Sign the application. From firmware/STM32CubeIDE/FSBL :

Remove-Item -Force "Debug\MedSight_ssbl.bin" -ErrorAction SilentlyContinue
& $SIGN -bin "Debug\MedSight_FSBL.bin" -nk -t ssbl -hv 2.3 -la 0x34000000 -align -o "Debug\MedSight_ssbl. bin"
FLAG | WHY
-t ssbl | second stage. -t fsbl produces an image the ROM can never load, because of the 512 KB cap. Getting this wrong costs an afternoon, so it is worth checking twice
-hv 2.3 | the boot header version the ROM expects
-la 0x34000000 | load address, must match the linker script
-nk | no signing key; the board is not in a secured state
-align | pad to the alignment the loader requires

Flash both stages:

& $CLI -c port=SWD mode=UR -el $LOADER -w "<path>\ai_fsbl.hex"
& $CLI -c port=SWD mode=UR -el $LOADER -w "Debug\MedSight_ssbl.bin" 0x70100000 -v

Use -v . Verify the whole file. Do not check a few bytes of a magic number and call it confirmed: during bring-up that produced a "verified" write that had not happened, because both candidate images shared those bytes.

Then unplug the cable, set SW1 LOW, and power it from anything 5 V. To get back to Mode A, set SW1 HIGH; nothing is erased.

### 8.9 Running with no dispensing hardware

Fully supported, and it is how a reviewer without a stepper motor should build this. In
firmware/FSBL/Inc/dispenser.h :

#define MEDSIGHT_PHYSICAL_DISPENSER 0

Rebuild. Everything except the physical dispense still runs - face recognition, scheduling, carer mode, the audit log, all 22 screens - and the dispense itself is shown on screen instead of turned by a motor.

Both values build with 0 errors and 0 warnings, and the no-hardware branch is the earlier on-screen dispense kept byte-for-byte. It has been run on the assembled board, not merely compiled, and it is the configuration to use if the mechanism is unavailable.

### 8.10 Other switches

MACRO | FILE | DEFAULT EFFECT
MEDSIGHT_PHYSICAL_DISPENSER | Inc/dispenser.h | 1 | 0 = no hardware needed
MEDSIGHT_ACTION_RECOGNITION | Inc/ai/intake.h | 1 | 0 removes the intake pipeline entirely
MEDSIGHT_INTAKE_SIMPLE | Inc/ai/intake.h | 1 | 0 restores the full guarded intake state machine
MS_COIL_PINSET | Src/dispenser.c | 1 | 0 selects an alternative coil pin set
MS_DISPENSE_DIRECTION | Src/dispenser.c | (-1) | Anticlockwise. 1 reverses it
MS_NO_PILL_TIMEOUT_MS | Src/dispenser.c | 25000 | how long with no counted pill before JAM or SHORT
MEDSIGHT_FAST_CLOCK | build config | Debug
| | 1 | compresses a day into 24 minutes, so a dose window lasts 30 real seconds

Demo mode is worth knowing about. With MEDSIGHT_FAST_CLOCK , one simulated minute is one real second, so a window opening, being met, and a later one being missed all fit in one sitting. Release is the honest wall-clock build, and nothing above the time source knows which is behind it.

P A R T 9

# Troubleshooting

Device messages

THE SCREEN SAYS | WHAT HAPPENED | WHAT TO DO
JAM | 25 s with nothing
counted. Nothing
was released

Open the housing, check the turntable and chute. Give the dose by hand

NOT ENOUGH PILLS Some pills, then 25 s of nothing

Refill the turntable. Check how many the patient actually got: the log records what really came out

No memory card Card missing or not seated

Power off, reseat, power on. Nothing is recorded while this shows

The clock has never
been set
Exactly that | See 7.4. Doses cannot be scheduled until it is set

FACE NOT
RECOGNISED

The match failed TRY AGAIN, better light, face straight on. Re-enrol in the room's own light if it persists

Gallery full | Ten already
registered

Delete somebody

Nothing on screen, red
LED blinking about
twice a second

A startup fault. The
board never reached
the home screen

Most often the camera or LCD ribbon is not seated. Power off, reseat both, power on. See the lights table below

Nothing on screen | No power | Check the cable and the battery. Then check the power-source jumper on the underside of the board: it must be on USB-C to run from the battery, and on STLK to run from the debugger. A board on the wrong one is silent and looks broken
The turntable never moves, or the mechanism is damaged | The dispensing hardware is not working | The device does not need it. Rebuild with MEDSIGHT_PHYSICAL_DISPENSER 0 and the whole application runs with the dispense shown on screen instead. See 8.9

If the dispensing hardware is damaged or missing, nothing is lost. One macro and one rebuild runs the device without it, and 8.9 is the whole procedure.

A known intermittent, stated rather than hidden: the memory card occasionally fails to initialise at boot and recovers on its own. If the device starts up saying nobody is registered, power off, reseat the card, power on. The patients are still on it.

Board LEDs
Two LEDs on the board say what the firmware is doing, and one of them means the opposite of what people assume. Blinking red is not always a fault: the rate is the message.

LIGHT

WHAT IT LOOKS
LIKE

WHAT IT MEANS

Red Twice a second,
evenly, forever

A startup fault. The board stopped before the scheduler started, so nothing else is running. Almost always the camera or the LCD ribbon not seated

Red | Once a second | Normal. The lowest-priority task is running, which means the whole system is scheduling
correctly. This is the light you want
Red | Fast flicker | The camera pipeline is reporting errors while running
Green Steady or fast flicker | The camera pipeline is alive and processing frames

The camera is not optional. Unlike the dispensing hardware, which the device runs without (8.9), camera bring-up is part of mandatory startup: if the sensor does not answer, the firmware stops in its fault handler and blinks red. A device that blinks twice a second and shows nothing has almost certainly had a ribbon shaken loose.

During flashing

SYMPTOM | CAUSE | FIX

Boot log stops after ai_vision_init , screen
frozen

flash bus state after a loader operation

unplug the cable (8.2)

Networks initialise, outputs are nonsense | weights missing or at the wrong address

8.5

HOTPLUG connection or erase fails | MedSight is running and owns the bus

use mode=UR

Nothing boots in Mode B | signed -t fsbl , or wrong address re-sign -t ssbl , write to
0x70100000
Stepper does nothing, driver LEDs dark | ground not shared, or wrong pins | Part 5
No file system is defined for scheme: C | forward slashes in a headless import path | use backslashes

P A R T 1 0

# Current limitations and planned work

MedSight works. It dispenses real pills, counts them, recognises the patient and keeps a record, on its own power, with no computer attached.

It is a prototype, and five things are not done yet. Each has a plan.

One medication at a time. One turntable means one medication, and the record stores a count rather than a drug name. Next: the six to eight stacked dispensing modules described in Part 5, plus a drug field in the patient record. The interface already draws four medication slots with three greyed out and labelled SOON, and the dispense function already takes a count and returns what was counted, so the firmware change is additive. The mechanical build is the work.

It does not know how much is on the turntable. The first sign of an empty one today is a dose that comes up short. Next, and the cheapest useful improvement in the list: a carer-entered "filled with N", decremented by counted pills rather than assumed ones, shown as a low-stock warning. It uses screens that already exist.

A missed dose cannot leave the room. There is no radio in this build, which kept the prototype achievable and means a missed dose waits for the carer's next round. Next, and the top of the roadmap: a carer alert over Wi-Fi and a patient-worn band that signals when a dose is due. The firmware hook already exists, since the scheduler fires exactly once per window, so the work is the radio, the provisioning and the security design: encrypted to a known endpoint, carrying the minimum that makes the alert actionable, with a deliberate answer to where the record comes to rest, and behaving exactly as it does today if the link is down.

The alerting side is planned as a separate companion unit first, proved on its own before any of it is folded into the dispenser, so that a fault in a radio can never take the dispensing path down with it. Folding it in afterwards means a flexible printed circuit in place of the loose harness this prototype uses, which is the step that turns two boxes into one product. All of it stays under the same open licence as the rest of this work.

The face check can be shown a photograph. Recognition compares a face against an enrolled fingerprint. It does not test whether the face in front of it is a live one, so a printed photograph or a phone screen held up to the camera would pass. In a shared room with a carer present that matters less than it would in an unattended machine, but it is a real gap and it belongs in the list rather than waiting to be discovered. Next: a liveness check on the same camera and the same accelerator the match already runs on. This sensor gives no depth, so the approach is the one that suits a single colour camera: a passive test for the texture and the small involuntary motion that a flat reproduction does not have, run on frames that are already being captured, before a match is accepted rather than after.

The housing does not lock. It is a printed prototype shell, which matters because care regulations in most places require medication to be stored locked. The device does withhold - it refuses a dose outside its window and to a face it does not recognise - but it does not lock. Next: a lockable enclosure, tamper detection, and a vibration sensor so the log can say when the unit was shaken. Logging is the whole response: a dispenser that stops working because it was jostled is a hazard.

And one thing worth being clear about. The device counts pills leaving the turntable and corroborates a swallowing gesture; it cannot prove somebody swallowed, and no device of this class can. That is why the button the patient presses remains the confirming action and the camera's verdict is evidence in the log rather than the verdict. Face matching is likewise a similarity score rather than an identity guarantee. Testing so far is four dispense trials, 13 of 13 pills, with no deliberately induced jam and no trial with the people the device is designed for. That is the honest state of a working prototype, and it is what the next round of work is for.

T H A N K Y O U
MedSight was built by five of us.

Dousik Manokaran
A P P L I C A N T

The firmware: the µT-Kernel migration, the six-task architecture and its priorities, the four networks on the accelerator, and this handbook.

Howard Nikhil | The physical dispensing hardware: the turntable, the infrared pill counter, and the bench work the counting design rests on.
Gaurav V R & Dillimaran K | The three-stage intake pipeline - detection, geometry, temporal decision - and the guarded state machine that refuses to certify an intake it cannot support.
Abirami M | The visual identity: the mascot, and the artwork all twenty- two screens are cut from.
Dr. G. Santhanamari & Dr. D. Selvakumar | Supervision, and two roadmap items: the vibration sensor for tamper detection, and the patient-worn alert band.

Our thanks to the TRON Forum for the opportunity, and for the STM32N6570-DK board that made the second round possible. Building on µT-Kernel 3.0 at this scale was the part we enjoyed most: the task priorities here are derived rather than argued, the four networks run on the board's own accelerator, and every number in this handbook came off the device.

We would like to keep going: the radio, the extra dispensing modules, and a trial with the people this is actually for. Thank you for reading.

µT-Kernel 3.0 is © TRON Forum and Ken Sakamura under T-License 2.1 / 2.2, and the board was supplied by the TRON Forum. MedSight's own code, documentation and CAD are Apache-2.0. Third-party components and their licences are inventoried in THIRD_PARTY_SOFTWARE.md.

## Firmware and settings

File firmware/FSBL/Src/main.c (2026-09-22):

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
/* Includes ------------------------------------------------------------------*/
#include "main.h"

/* USER CODE BEGIN Includes */
#include "isp_api.h"
#include "imx335_E27_isp_param_conf.h"
#include "ui/anime_ui.h"
#include "ui/state_machine.h"
#include "sd_logger.h"
#include "ai_vision.h"
#include "ms_osal.h"    /* All RTOS access goes through OSAL */
#include "schedule_time_source.h" /* RTC-backed dose scheduling  */
#include "dispenser.h"  /* Stepper turntable + IR pill counter */
#include "buzzer.h"     /* The Program Plan's Alert Task           */
#include <string.h>     /* Strstr() in __assert_func() below */
/* USER CODE END Includes */

/* USER CODE BEGIN PD */

/* The earlier boot-hang bring-up instrumentation - the solid
 * LED checkpoints and the six per-step GREEN blinks through camera/LCD
 * bring-up - is now compile-time gated and OFF by default. It cost ~3.7 s of
 * blinking on every single boot (six blinks of 620 ms plus a 1 s checkpoint-4
 * burst) for a hang that was root-caused and
 * fixed long ago. The cleanup that followed stripped the vendored kernel
 * tree but missed main.c, so this closes it
 * out. Kept gated rather than deleted because it is genuinely the right first
 * tool if the board ever goes dark before UART comes up again - set this to 1
 * and it is all back, unchanged.
 * NOTE this does NOT touch Error_Handler()'s own blinking RED, which is a
 * permanent fault indicator, not instrumentation. */
#ifndef MS_BOOT_LED_CHECKPOINTS
#define MS_BOOT_LED_CHECKPOINTS   0
#endif

/* How often task_heartbeat_fn prints the idle/power figure.
 * 10 s is frequent enough to watch a change take effect on the bench and
 * infrequent enough that it never competes with the flow's own logging. */
#define MS_IDLE_REPORT_MS   10000u

/* ════════════════════════════════════════════════════════════════════════
 * MS_DISPLAY_WATCH - diagnostic for the cold-boot "draws, fades, greys out"
 * fault, added after four wrong diagnoses.
 *
 * Every guess so far has been about a *mechanism*. This measures the two
 * things that would tell those mechanisms apart, once a second, from the
 * lowest-priority task:
 *
 *   1. Is the framebuffer's CONTENT changing after the home screen is drawn?
 *      A sampled checksum, read back from RAM (not from cache), plus the
 *      DCMIPP frame counter. If the checksum moves, something is writing
 *      over the display buffer and the only question left is who. If
 *      NbMainFrames is also climbing, the answer is the camera: main() starts
 *      DCMIPP PIPE1 into BUFFER_ADDRESS in CONTINUOUS mode before the
 *      scheduler, and state_machine_init()'s camera_stop() is supposed to end
 *      that.
 *
 *   2. Is the LTDC still SCANNING, and still scanning the right address?
 *      GCR.LTDCEN, layer 1 CR.LEN and CFBAR, plus CDSR - the live
 *      HSYNC/VSYNC/HDE/VDE status bits. If the checksum is rock steady and
 *      CDSR goes quiet or LTDCEN drops, the memory is fine and the fault is
 *      the controller or the panel, which is a completely different search.
 *
 * Also prints the three panel control pins, since PQ6 (LCD_BL_CTRL) going
 * low is literally "the screen fades".
 *
 * This is a bench instrument, not a feature. Set it to 0 once the fault is
 * understood - and unlike MS_BOOT_SETTLE_MS, do not let it quietly become
 * load-bearing: it only reads registers and memory, it changes nothing.
 * ════════════════════════════════════════════════════════════════════════ */
#ifndef MS_DISPLAY_WATCH
#define MS_DISPLAY_WATCH 0   /* bench instrument; see Addendum 9 */
#endif
#define MS_DISPLAY_WATCH_MS  1000u

/* USER CODE END PD */

/* USER CODE BEGIN PM */

/* Calculate division factor for a given source and destination dimension */
#define DIV_FACTOR(SRC, DST) (((uint32_t)((1024 * DST) / SRC)) > 1023 ? 1023 : ((uint32_t)((1024 * DST) / SRC)))

/* Calculate down scale ratio in unsigned 3.13 fixed-point format */
#define DOWNSCALE_RATIO(SRC, DST) (((uint32_t)(((float_t)(SRC) / (float_t)(DST)) * 8192) < 8192) ? 8192 : \
                                   ((((uint32_t)(((float_t)(SRC) / (float_t)(DST)) * 8192)) > 65535) ? 65535 : \
                                   ((uint32_t)(((float_t)(SRC) / (float_t)(DST)) * 8192))))
/* USER CODE END PM */

DCMIPP_HandleTypeDef hdcmipp;
LTDC_HandleTypeDef   hltdc;
ISP_HandleTypeDef    hcamera_isp;
SD_HandleTypeDef     hsd2;
DMA2D_HandleTypeDef  hdma2d;

/* USER CODE BEGIN PV */
static __IO uint32_t NbMainFrames = 0;
static IMX335_Object_t   IMX335Obj;
static int32_t isp_gain;
static int32_t isp_exposure;
/* USER CODE END PV */

void SystemClock_Config(void);
void PeriphCommonClock_Config(void);
static void MX_DCMIPP_Init(void);
static void LCD_Init(uint32_t Width, uint32_t Height);
static void MX_SDMMC2_SD_Init(void);
/* USER CODE BEGIN PFP */
static void IMX335_Probe(uint32_t Resolution, uint32_t PixelFormat);
static ISP_StatusTypeDef GetSensorInfoHelper(uint32_t Instance, ISP_SensorInfoTypeDef *SensorInfo);
static ISP_StatusTypeDef SetSensorGainHelper(uint32_t Instance, int32_t Gain);
static ISP_StatusTypeDef GetSensorGainHelper(uint32_t Instance, int32_t *Gain);
static ISP_StatusTypeDef SetSensorExposureHelper(uint32_t Instance, int32_t Exposure);
static ISP_StatusTypeDef GetSensorExposureHelper(uint32_t Instance, int32_t *Exposure);
/* USER CODE END PFP */

/* USER CODE BEGIN 0 */

/* ════════════════════════════════════════════════════════════════════════════
 * TASK DEFINITIONS, and where their priorities come from
 *
 * ── The priority scheme, and where the numbers come from ──────────────────
 *
 * Earlier builds used 5/4/2/1 with the ordering argued informally ("camera
 * must never be starved", "touch should feel immediate"). The ordering was
 * right; the numbers had never been justified against each task's actual
 * period and deadline. They were then derived properly, rate-monotonic
 * style - shortest period gets the highest priority - and the result agrees
 * with what was already there, which is why nothing was renumbered. The one
 * change is that the previously-vacant level 3 is now occupied by the new
 * NPU task, deliberately placed BELOW the UI.
 *
 *  pri | task            | period      | deadline / why it sits there
 *  ----+-----------------+-------------+--------------------------------------
 *   5  | task_camera_isp | 1 ms        | Shortest period in the system and the
 *      |                 |             | only one tied to external hardware
 *      |                 |             | timing: ISP_BackgroundProcess() must
 *      |                 |             | consume each frame's statistics
 *      |                 |             | before the next VSYNC (~33 ms at
 *      |                 |             | 30 fps). Missing it degrades AE/AWB
 *      |                 |             | convergence, which is visible.
 *   4  | task_ui         | 10 ms       | Touch-to-response budget. Humans
 *      |                 |             | notice input lag past ~100 ms; a
 *      |                 |             | 10 ms poll plus the 4 FPS mascot
 *      |                 |             | frame gate keeps the whole UI an
 *      |                 |             | order of magnitude inside that.
 *      |                 |             | This matters, and there is
 *      |                 |             | measured evidence for it: when
 *      |                 |             | the kernel tick made these deadlines
 *      |                 |             | stretch 10x, the device immediately
 *      |                 |             | "felt slower than FreeRTOS".
 *   3  | task_ai         | on demand   | NO deadline. Hundreds of ms of solid
 *      |                 | (~0.5-4 s   | NPU/CPU work per request, a few
 *      |                 |  per burst) | times per session, in response to a
 *      |                 |             | button press the user already knows
 *      |                 |             | takes a moment. Placed below the UI
 *      |                 |             | on purpose: this is precisely the
 *      |                 |             | work that must be preemptible, so
 *      |                 |             | touch and the physical USER1 button
 *      |                 |             | keep responding while it runs. Above
 *      |                 |             | the logger because the user is
 *      |                 |             | actively waiting on its result and
 *      |                 |             | nobody is waiting on a log line.
 *   2  | task_logger     | event-driven| Tolerates seconds of latency by
 *      |                 |             | construction - the async queue
 *      |                 |             | exists so callers never wait on an
 *      |                 |             | SD write (10-50 ms each, occasionally
 *      |                 |             | much worse on a slow card).
 *   1  | task_heartbeat  | 500 ms      | No deadline at all; it is a liveness
 *      |                 |             | indicator. Deliberately lowest so
 *      |                 |             | that "the LED stopped blinking" means
 *      |                 |             | "something above me is starving the
 *      |                 |             | system", which is exactly the signal
 *      |                 |             | you want it to carry.
 *
 * ms_osal.h's convention is 1 = lowest; ms_osal.c inverts it onto
 * µT-Kernel's opposite scale (1 = highest) as OSAL_PRI_CEILING - priority,
 * so 5/4/3/2/1 become itskpri 11/12/13/14/15. Only the ordering is load
 * bearing; the absolute numbers leave headroom on both sides inside
 * mtk3_bsp2's CNF_MAX_TSKPRI of 32.
 *
 * Stack sizes are in 32-bit WORDS:
 *   2048 words = 8 KB  - UI (deep call chain through gui_draw/registration_ui)
 *                        and AI (the ST Edge AI runtime's own call depth; this
 *                        is the stack the pipeline already ran on when it was
 *                        part of the UI task, carried over unchanged rather
 *                        than re-tuned blind).
 *   1024 words = 4 KB  - adequate for FATFS local buffers (logger) and
 *                        the ISP middleware's background-processing locals.
 *   256 words  = 1 KB  - minimal, heartbeat has no deep callstack.
 * ════════════════════════════════════════════════════════════════════════════ */

/* ── Task: Camera / ISP background processing ───────────────────────────── */
/* Priority 5 - highest. ISP_BackgroundProcess() must run every frame period.
 * Running it in a dedicated task prevents UI/logging jitter from delaying it. */
static void task_camera_isp_fn(void *arg)
{
    (void)arg;
    printf("task_camera_isp: started.\r\n");

    for (;;) {
        BSP_LED_Toggle(LED_GREEN);
        if (ISP_BackgroundProcess(&hcamera_isp) != ISP_OK) {
            BSP_LED_Toggle(LED_RED);
        }
        /* Yield for 1 tick (1ms) - ISP needs to run once per frame (~30fps),
         * so 1ms sleep is faster than needed but ensures other tasks get CPU.
         * The ISP library is self-throttling internally. */
        osal_delay_ms(1u);
    }
}

/* ── Task: UI - touch polling, state machine, mascot animation ─────────── */
/* Priority 4 - second-highest. Touch events polled every 10ms = 100Hz.
 * This gives ≤10ms touch-to-response latency, well within "immediate" feel.
 * The mascot animation self-throttles to 4 FPS inside anime_ui_update().   */
static void task_ui_fn(void *arg)
{
    (void)arg;
    printf("task_ui: started.\r\n");

    /* state_machine_init() configures touch IC, draws home screen, etc.
     * Called here (inside the task) because some BSP functions need the
     * RTOS scheduler already running to use HAL I2C blocking functions
     * correctly. */
    state_machine_init();
    SD_Log_Event_Async("System Boot - MedSight on uT-Kernel 3.0");

    /* Ai_vision_init() no longer runs here. It used to do the
     * one-time NPU + gallery bring-up on this task because inference itself
     * was a synchronous call from state_machine_update(); it now lives in
     * task_ai_fn (ai_vision.c), which is the task that owns the NPU. */

    for (;;) {
        state_machine_update();
        /* 10ms poll period: responsive touch without burning CPU.
         * anime_ui_update() inside state_machine_update() uses HAL_GetTick()
         * for its own 250ms frame gate - unaffected by this sleep. */
        osal_delay_ms(10u);
    }
}

/* ── Task: Logger - dequeue and write to SD ─────────────────────────────── */
/* Priority 2 - low. SD writes can take 10-50ms; other tasks preempt freely.
 * task_logger_fn is defined in sd_logger.c (the log queue is private there). */

/* ── Task: Heartbeat - liveness LED blink ───────────────────────────────── */
/* Priority 1 - lowest. If this stops blinking, the scheduler has stalled.
 * Blink period: 500ms on, 500ms off = 1Hz. */
#if MS_DISPLAY_WATCH
/* Sampled checksum of the framebuffer, read from RAM rather than from cache.
 *
 * Clean-then-invalidate, not plain invalidate: a plain invalidate would throw
 * away any dirty lines the UI task had not flushed yet and corrupt the very
 * picture we are trying to observe. Cleaning first pushes our own writes out,
 * so what we then read back is exactly the bytes LTDC's DMA sees. */
static uint32_t framebuffer_sample_checksum(void)
{
    uint32_t sum = 0u;
    /* 32 rows spread down the screen, one 32-byte cache line each: enough to
     * catch any large-area overwrite, cheap enough to run once a second on
     * the lowest-priority task. */
    for (uint32_t i = 0u; i < 32u; i++) {
        uint32_t row  = (i * FRAME_HEIGHT) / 32u;
        uint32_t addr = (BUFFER_ADDRESS + row * FRAME_WIDTH * 2u) & ~31u;
        SCB_CleanInvalidateDCache_by_Addr((uint32_t *)addr, 32);
        const volatile uint32_t *p = (const volatile uint32_t *)addr;
        for (uint32_t w = 0u; w < 8u; w++) {
            sum = (sum * 31u) + p[w];
        }
    }
    return sum;
}
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
int main(void)
{
    /* USER CODE BEGIN 1 */
    ISP_AppliHelpersTypeDef appliHelpers = {0};
    /* USER CODE END 1 */

    /* Enable the CPU Cache */
    SCB_EnableICache();
    SCB_EnableDCache();

    /* MCU Configuration */
    HAL_Init();

    /* Configure the system clock */
    SystemClock_Config();

    /* Configure the peripherals common clocks */
    PeriphCommonClock_Config();

    /* USER CODE BEGIN SysInit */

    /* ════════════════════════════════════════════════════════════════════
     * Declare EVERY I/O supply domain valid before touching
     * a single GPIO.
     *
     * The STM32N6's high-numbered GPIO banks are split across separately
     * supplied I/O domains (VDDIO2..VDDIO5), and a bank whose domain has not
     * been declared valid does not drive its pins. This project hit that
     * early on, when a missing
     * HAL_PWREx_EnableVddIO5() left the SDMMC2 pins unpowered and the driver
     * hung forever waiting on hardware that could not answer.
     *
     * The same trap was still live for the display, and much harder to see.
     * Mapping the domains from the ST BSP's own call sites:
     *
     *     VDDIO2 -> GPIOO      (BSP_LED_Init)
     *     VDDIO3 -> GPION      (SD card-detect)
     *     VDDIO4 -> GPIOH      (I2C1, camera)
     *     VDDIO5 -> GPIOC/E    (SDMMC2)
     *
     * LTDC's MspInit configures PE11 (LCD_VSYNC), PE1 (touch NRST) and
     * PH3/PH4/PH6 (colour bits B4/R4/B5) - i.e. pins in the VDDIO5 and
     * VDDIO4 domains - and enables NEITHER. Nothing enabled VDDIO5 until the
     * SD card was initialised, long after the panel had been configured and
     * the LTDC had started scanning out.
     *
     * Why this hid for so long: the PWR SVMCR "supply valid" bits live in the
     * always-on power domain and are NOT cleared by a system reset - only by
     * actually removing power. So once any run had enabled them, every
     * subsequent flash-and-run inherited valid domains and the display came up
     * fine. The bug only appears on a true cold boot, which is exactly the
     * situation the display fails in: dark, ghosting, fading out, while UART
     * (USART1, on the main VDD domain) carries on perfectly.
     *
     * Enabling all four here, once, before any peripheral init, removes the
     * ordering dependency entirely. The bits are idempotent, every one of
     * these rails is populated and powered on the STM32N6570-DK, and the BSP's
     * own later calls become harmless no-ops.
     * ════════════════════════════════════════════════════════════════════ */
    HAL_PWREx_EnableVddIO2();
    HAL_PWREx_EnableVddIO3();
    HAL_PWREx_EnableVddIO4();
    HAL_PWREx_EnableVddIO5();

    BSP_LED_Init(LED_GREEN);
    BSP_LED_Init(LED_RED);

    /* Bring-up checkpoint 1 - see MS_BOOT_LED_CHECKPOINTS above.
     * Cache enable, HAL_Init(), SystemClock_Config(),
     * PeriphCommonClock_Config() and LED GPIO init all completed.
     * Solid GREEN = passed checkpoint 1. */
#if MS_BOOT_LED_CHECKPOINTS
    BSP_LED_On(LED_GREEN);
#endif

    /* UART log */
#if USE_COM_LOG
    COM_InitTypeDef COM_Init;
    COM_Init.BaudRate   = 115200;
    COM_Init.WordLength = COM_WORDLENGTH_8B;
    COM_Init.StopBits   = COM_STOPBITS_1;
    COM_Init.Parity     = COM_PARITY_NONE;
    COM_Init.HwFlowCtl  = COM_HWCONTROL_NONE;
    BSP_COM_Init(COM1, &COM_Init);
    if (BSP_COM_SelectLogPort(COM1) != BSP_ERROR_NONE) {
        Error_Handler();
    }
#endif
    /* USER CODE END SysInit */

    /* Checkpoint 2: UART/COM init (BSP_COM_Init, BSP_COM_SelectLogPort)
     * completed without Error_Handler firing. Solid GREEN+RED. */
#if MS_BOOT_LED_CHECKPOINTS
    BSP_LED_On(LED_RED);
#endif

    /* Per-step blink through the six camera/LCD bring-up calls below. RED
     * stays solid throughout (it only starts BLINKING if Error_Handler()
     * fires); count the GREEN blinks to see exactly how far boot gets.
     *
     * NOTE: this is now purely visual. The *timing* those blinks used to
     * provide has been separated out into _MS_SETTLE() below - see the
     * MS_BOOT_SETTLE_MS comment. Turning the blinks on or off no longer
     * changes whether the display comes up. */
#if MS_BOOT_LED_CHECKPOINTS
#define _MS_BLINK() do { BSP_LED_On(LED_GREEN); HAL_Delay(120); \
                          BSP_LED_Off(LED_GREEN); HAL_Delay(500); } while (0)
#else
#define _MS_BLINK() do { } while (0)
#endif

/* ════════════════════════════════════════════════════════════════════════
 * Boot settling - kept as a knob, set to zero, and here is why
 *
 * Earlier builds had ~4.7 s of accidental delay through the camera/LCD
 * bring-up below: six _MS_BLINK() calls at 620 ms plus a 1 s LED burst before
 * the scheduler, all of it bring-up instrumentation. Once the blinks were
 * gated off as dead weight, the display started failing from a
 * cold boot, and the obvious conclusion was that the delay had been
 * load-bearing. So it was reinstated here as an explicit, measured,
 * bisectable value.
 *
 * That conclusion was WRONG, and this is the record of it. The fault was
 * reproduced on hardware with 5.6 s of settling applied and it still failed.
 * The real cause was the WFI added to the kernel idle path gating the clocks
 * the LTDC needs - see ms_configure_sleep_clocks() below.
 * No part of the bring-up sequence needs any
 * settling time at all, which is why both values are now zero: boot goes
 * straight through in a few hundred milliseconds.
 *
 * The knobs stay because they cost nothing and because a future bring-up on
 * different hardware may genuinely want them. But do not reach for them to
 * explain a fault. The lesson here is the opposite one: when
 * something that worked stops working, suspect what you changed, and measure
 * before theorising. Four hardware-shaped theories were wrong here before a
 * single measurement settled it.
 * ════════════════════════════════════════════════════════════════════════ */
#ifndef MS_BOOT_SETTLE_MS
#define MS_BOOT_SETTLE_MS          0u     /* none needed - see the note above */
#endif
#ifndef MS_BOOT_PRESCHED_SETTLE_MS
#define MS_BOOT_PRESCHED_SETTLE_MS 0u     /* none needed - see the note above */
#endif

/* Boot progress over UART, with timings. Cheap, one line per step, and it is
 * what makes MS_BOOT_SETTLE_MS tunable instead of guessed. On by default
 * while the cold-boot display fault is being confirmed fixed. */
#ifndef MS_BOOT_TRACE
#define MS_BOOT_TRACE 0
#endif

#if MS_BOOT_TRACE
#define _MS_SETTLE(step)                                                      \
    do {                                                                      \
        uint32_t _t_done = HAL_GetTick();                                     \
        printf("boot: %-22s done at %lums (step took %lums), settling %ums\r\n", \
               (step), (unsigned long)_t_done,                                \
               (unsigned long)(_t_done - _ms_boot_mark), MS_BOOT_SETTLE_MS);  \
        _MS_BLINK();                                                          \
        HAL_Delay(MS_BOOT_SETTLE_MS);                                         \
        _ms_boot_mark = HAL_GetTick();                                        \
    } while (0)
#else
#define _MS_SETTLE(step)                                                      \
    do { _MS_BLINK(); HAL_Delay(MS_BOOT_SETTLE_MS); } while (0)
#endif

    /* Timing mark used by _MS_SETTLE()'s trace. */
    uint32_t _ms_boot_mark = HAL_GetTick();
    (void)_ms_boot_mark;
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

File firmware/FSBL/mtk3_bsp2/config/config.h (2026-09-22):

/*
 *----------------------------------------------------------------------
 *    micro T-Kernel 3.0 BSP 2.0
 *
 *    Copyright (C) 2023-2024 by Ken Sakamura.
 *    This software is distributed under the T-License 2.1.
 *----------------------------------------------------------------------
 *
 *    Released by TRON Forum(http://www.tron.org) at 2024/02.
 *
 *----------------------------------------------------------------------
 */

#ifndef _MTKBSP_TK_CONFIG_
#define _MTKBSP_TK_CONFIG_
/*
 *	config.h
 *	User Configuration Definition
 */
/*---------------------------------------------------------------------- */
/* SYSCONF: micro T-Kernel system configuration
 */

#define	CNF_SYSTEMAREA_TOP	0	/* 0: Use system default address */
/* MedSight fix: 0 ("use system default") makes sys_start.c use
 * INTERNAL_RAM_END, which sysdepend/stm32_cube/cpu/stm32n6/sysdef.h defines
 * as the end of the *entire physical* AXI SRAM0 bank (0x341FFF00) - the
 * full 2047KB, not this project's own linker-script "RAM" region, which is
 * only the first 1023KB of that same bank (STM32N657X0HXQ_AXISRAM2_fsbl.ld:
 * RAM ORIGIN=0x34000400 LENGTH=1023K, ending at 0x34100000). The bytes in
 * between (0x34100000-0x34180400) and this project's own "ROM" linker
 * region for.text/.rodata (0x34180400-0x34200000, ending exactly where the
 * camera framebuffer at 0x34200000 begins) are NOT free memory in this
 * project - they hold running code. Left at the vendored default, µT-Kernel's
 * dynamic allocator (imalloc, backing tk_cre_tsk's stacks, tk_cre_mbf's
 * buffers, tk_cre_cyc's control blocks) would hand out memory inside that
 * "ROM" range the first time anything is created in usermain(), corrupting
 * this project's own code with zero warning and no UART output - exactly
 * the silent hang into Default_Handler this fix addresses. Pinning
 * CNF_SYSTEMAREA_END to this project's actual RAM-region end keeps the
 * kernel's heap inside memory this project's linker script actually reserves
 * for dynamic use.
 *
 * This constant and the linker script's MEMORY block are
 * ONE decision and must always move together.
 *
 * ROM and RAM are swapped so the loadable image sits where ST's
 * two-stage boot loader expects it (see the linker script's own note on why).
 * RAM is now 0x34100000-0x341FFFFF, so the kernel's heap ceiling follows it
 * to 0x34200000 - still exactly where the camera framebuffer begins, which is
 * the real physical boundary this value has always been tracking.
 *
 * Changing the linker script and leaving this at 0x34100000 produced a silent
 * hang on hardware, and it is worth recording precisely because it looks like
 * nothing:.bss moved up with the RAM region, so _end landed at 0x341A3890,
 * ABOVE the old ceiling. knl_lowmem_top then exceeded knl_lowmem_limit, the
 * kernel heap had negative size, every tk_cre_* in usermain() failed, and the
 * scheduler started with no tasks. The board printed its whole pre-kernel
 * boot log and then stopped between "sleep clocks:" and "task_camera_isp:
 * started." with no fault, no Error_Handler and nothing on UART. */
#define CNF_SYSTEMAREA_END	0x34200000

#define	CNF_MAX_TSKPRI		32	/* Task Max priority */

/* MedSight fix: the vendored default (10 ms) is a 10x
 * regression against the FreeRTOS build this project was written on, in two
 * compounding ways:
 *   1. tk_dly_tsk() granularity. main.c's camera/ISP task sleeps
 *      osal_delay_ms(1) per iteration and the UI task osal_delay_ms(10);
 *      at a 10 ms tick both round up to the next tick boundary, so the ISP
 *      loop ran at a tenth of its intended rate and touch polling at half.
 *   2. ms_osal.c's HAL tick bridge. HAL_IncTick() adds ONE to uwTick per
 *      call, so firing it every 10 ms made HAL_GetTick() advance 1 ms per
 *      10 ms of real time - HAL's whole millisecond clock ran 10x SLOW, not
 *      merely 10x coarse. Every HAL_GetTick()-based deadline in the UI
 *      stretched by 10x: the mascot's 250 ms animation frame gate
 *      (anime_ui.h LUMIO_FRAME_MS) became 2.5 s, so 0.4 FPS instead of 4,
 *      and state_machine.c's 500 ms touch dwell guard became 5 s - which is
 *      what "the buttons feel unresponsive" actually was.
 * 1 ms matches what FreeRTOS's tick did, is within this port's own
 * MIN_TIMER_PERIOD..MAX_TIMER_PERIOD (1..50, see
 * include/sys/sysdepend/stm32_cube/cpu/stm32n6/sysdef.h), and costs the same
 * 1 kHz timer ISR the FreeRTOS build already paid for. ms_osal.c's
 * OSAL_HAL_TICK_PERIOD_MS is derived from this macro so the two can no
 * longer drift apart. */
#define CNF_TIMER_PERIOD	1	/* System timer period */
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

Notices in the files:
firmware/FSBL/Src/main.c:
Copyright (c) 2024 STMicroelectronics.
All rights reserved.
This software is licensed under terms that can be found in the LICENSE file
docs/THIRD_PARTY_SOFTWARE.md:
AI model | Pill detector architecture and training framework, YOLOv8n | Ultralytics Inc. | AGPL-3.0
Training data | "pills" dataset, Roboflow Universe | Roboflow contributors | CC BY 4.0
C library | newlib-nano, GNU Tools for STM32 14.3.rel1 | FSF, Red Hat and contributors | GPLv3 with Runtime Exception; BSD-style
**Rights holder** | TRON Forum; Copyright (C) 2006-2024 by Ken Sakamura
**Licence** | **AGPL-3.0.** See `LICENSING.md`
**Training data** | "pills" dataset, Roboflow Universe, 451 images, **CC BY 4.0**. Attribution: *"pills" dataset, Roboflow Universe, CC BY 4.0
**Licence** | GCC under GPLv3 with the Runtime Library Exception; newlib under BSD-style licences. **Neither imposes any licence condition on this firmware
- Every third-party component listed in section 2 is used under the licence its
